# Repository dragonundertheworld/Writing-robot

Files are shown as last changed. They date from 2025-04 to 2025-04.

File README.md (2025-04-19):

# Robotic Pen‑Lifting Mechanism

A modular, servo‑driven pen‑lifting module with a central support bracket, designed for CNC‑style drawing robots, whiteboard plotters, or calligraphy machines. This repository contains CAD models, dimension sheets, and documentation for each major component and its iterative design process.

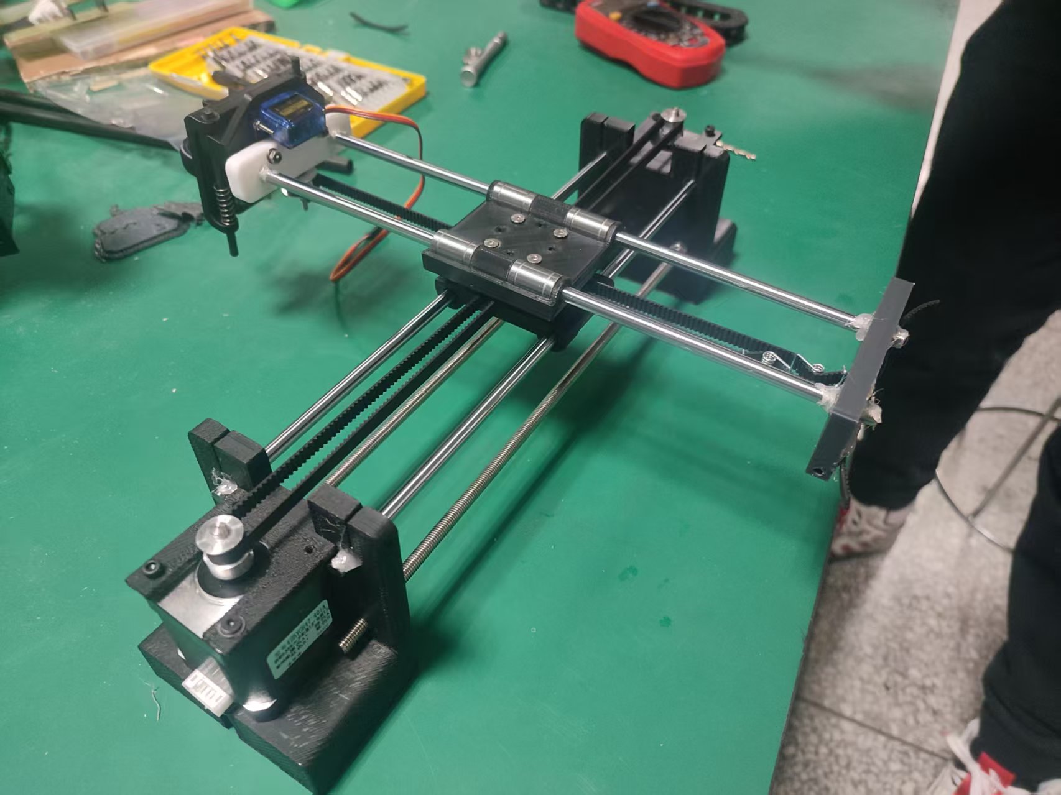
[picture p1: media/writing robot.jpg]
writing robot


Video of writing ["不忘初心"](./media/不忘初心.mp4) and ["你干嘛哎呦"](./media/你干嘛哎呦.mp4)
---

## Table of Contents

- [Robotic Pen‑Lifting Mechanism](#robotic-penlifting-mechanism)
      - [Video of writing "不忘初心" and "你干嘛哎呦"](#video-of-writing-不忘初心-and-你干嘛哎呦)
  - [Table of Contents](#table-of-contents)
  - [Project Overview](#project-overview)
  - [Key Features](#key-features)
  - [Mechanical Design](#mechanical-design)
    - [Central Support Bracket](#central-support-bracket)
    - [Pen‑Lifting Mechanism \& Servo Bracket](#penlifting-mechanism--servo-bracket)
  - [Integration \& Assembly](#integration--assembly)
  - [Bill of Materials](#bill-of-materials)
  - [CAD \& Drawings](#cad--drawings)
  - [Future Improvements](#future-improvements)
  - [License](#license)

---

## Project Overview

This project implements a **pen‑lifting subsystem** that can be mounted on a 2‑axis gantry or delta robot. It consists of:

- A **central support bracket** that holds the lifting assembly above the work surface.
- A **servo‑driven pen‑lift** that raises and lowers the drawing tool with sub‑millimeter precision.
- Modular interfaces for smooth rods and mounting plates, allowing quick integration into larger plotting systems.

---

## Key Features

- **Stable Central Support**  
  High‑rigidity bracket minimizes wobble during fast movements.  
- **Precision Pen Lift**  
  Servo‑cam mechanism provides repeatable up/down strokes.  
- **Modular Interfaces**  
  Standard M3‑hole pattern for linear guides, servos, and carriage plates.  
- **Iterative‑Driven Design**  
  Multiple CAD versions refined for weight, stiffness, and ease of assembly.

---

## Mechanical Design

### Central Support Bracket

1. **Principle**  
   - Acts as the backbone for the pen‑lifting module.  
   - Transfers loads from the carriage to the linear guide rails.  
2. **Dimension Design**  
   - Inner width: 40 mm to clearance standard guide blocks.  
   - Plate thickness: 5 mm aluminum for stiffness.  
   - Servo‑arm clearance zone: 25 mm × 15 mm cut‑out.  
3. **Iteration Process**  
   - **v1.0**: Solid plate—too heavy, resonance at 20 Hz.  
   - **v1.1**: Lightening pockets added—reduced mass by 30%.  
   - **v2.0**: Reinforced rib under servo mount—eliminated flex under 1 kg load.

### Pen‑Lifting Mechanism & Servo Bracket

1. **Lifting Principle**  
   - A high‑torque micro‑servo drives a cam‑follower arm.  
   - Cam profile converts 60° of servo travel into 10 mm vertical stroke.  
2. **Servo Bracket & Pen‑Lift Dimensions**  
   - Servo mount hole spacing: 32 mm × 16 mm (MG90S‑compatible).  
   - Cam arm length: 45 mm from pivot to pen holder.  
   - Guide rod interface: 8 mm bore with PTFE sleeve.  
3. **Component Mating**  
   - **Rod ↔ Pen‑lift arm**: 2 mm set‑screw clamps.  
   - **Pen‑lift arm ↔ Servo bracket**: 3 mm shoulder bolt pivot.  
   - **Rod ↔ Servo bracket**: Linear bushing ensures vertical alignment.  
4. **Iteration Processes**  
   - **Servo Bracket v1.0**: Over‑constrained, binding at extremes.  
   - **Servo Bracket v1.1**: Added +/-0.5 mm clearance pockets.  
   - **Pen‑lift Arm v1.0**: Cam profile too aggressive—jerky motion.  
   - **Pen‑lift Arm v1.1**: Smoothed cam radius; reduced stroke acceleration.

---

## Integration & Assembly

1. **Linear Rail Mounting**  
   - Slide central support onto two parallel 12 mm rails.  
   - Secure with four M3 × 10 mm cap screws.  
2. **Servo & Arm Installation**  
   - Attach servo to bracket using M2.5 hardware.  
   - Fit cam‑arm pivot, align pen holder vertically.  
3. **Pen Holder & Rod**  
   - Slide PTFE sleeve into bracket bore.  
   - Insert 8 mm hardened steel rod; fix pen holder to arm end.  
4. **Cable Routing**  
   - Use zip‑ties along bracket ribs.  
   - Ensure servo cable has >30 mm slack at extremes.

---

## Bill of Materials

| Item | Qty  | Notes |
|---|---|---|
| 5 mm Aluminum Plate (central bracket) | 1 | 100 × 60 mm, 6061‑T6 |
| MG90S Micro‑Servo | 1 | 180° travel, 2.2 kg·cm torque |
| 8 mm Hardened Steel Rod | 1 | Cut to 80 mm length |
| Linear Bushing (8 mm ID) | 2 | PTFE‑lined for smooth lift |
| M3 × 10 mm Cap Screws & T‑nuts | 4 | Rail mounting |
| M2.5 × 8 mm Screws & Nuts | 2 | Servo mount |
| M3 × 6 mm Shoulder Bolt & Washer | 1 | Cam pivot |
| PTFE Sleeve (8 mm ID) | 1 | Bore liner |
| Zip‑ties & Cable Clips | – | For cable management |

---

## CAD & Drawings

- **写字机器人建模/**
  - `中心支架下_Default_sldprt.STEP` — 支撑支架
  - `舵机旋转叶片_默认_sldprt.STEP` — 舵机安装座

---

## Future Improvements

- **Closed‑Loop Control**: Add hall‑sensor feedback for precise pen height.  
- **Quick‑Swap Carriage**: Magnetic couplers for sub‑60 s assembly changes.  
- **Lightweight Composites**: Replace aluminum with carbon‑fiber for weight reduction.  
- **Dampers**: Integrate silicone bumpers to soften pen‑up/down impacts.

---

## License

This work is released under the [MIT License](LICENSE). Feel free to adapt and integrate into your own plotting or drawing systems.

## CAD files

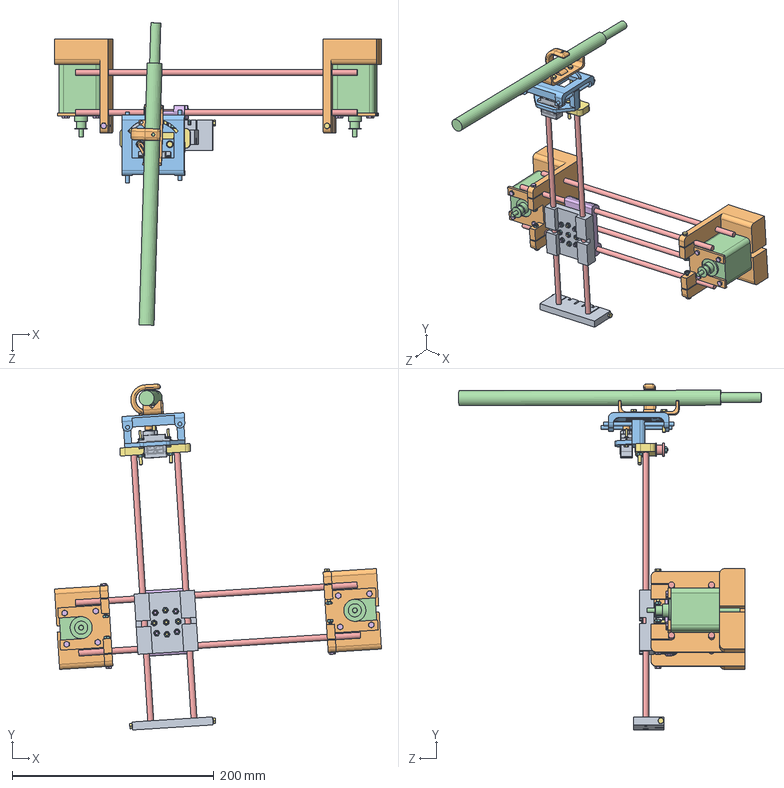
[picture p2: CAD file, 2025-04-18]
assets/写字机器人1.SLDASM
324.4 x 343.2 x 300.2 mm
base
motor_house x 2
Pen Carrige
motor1 x 2
光杆(丝杆) x 6
中心支架下
y_end2
惰轮 x 4
y_end1
Penholder
servoholder2
16齿主动轮 x 2
十六齿惰轮
hexagon head bolts-full thread gb x 15
hexagon head bolts gb x 15
hex nuts, style 1-grades ab gb x 20
SG90 - Micro Servo 9g - Tower Pro.1_Pe_X_87a
舵机旋转叶片
木棍 x 2
毛笔

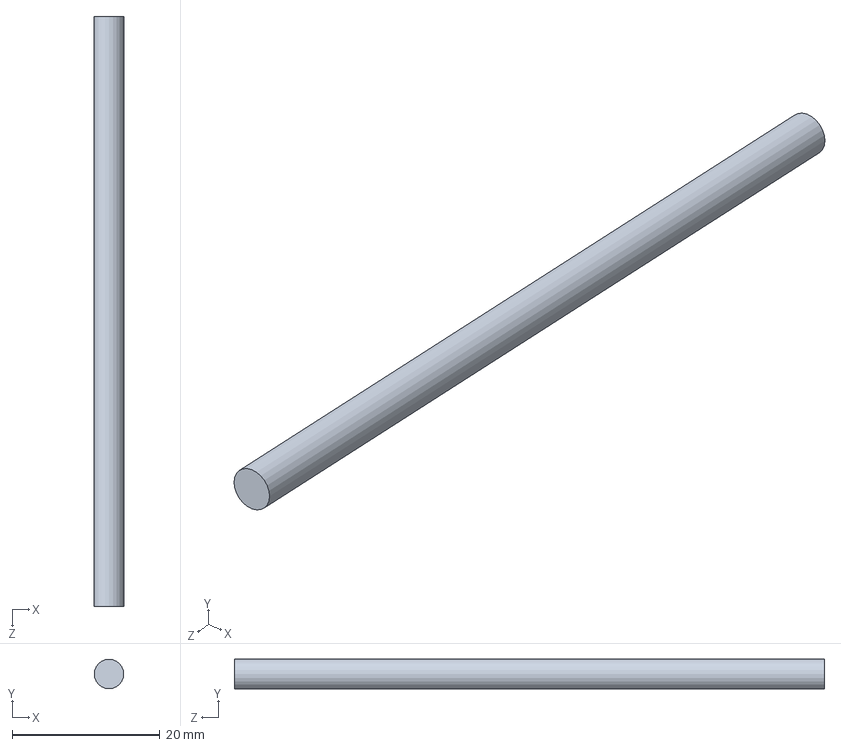
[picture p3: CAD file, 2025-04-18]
assets/木棍.SLDPRT
4.00 x 4.00 x 80.0 mm

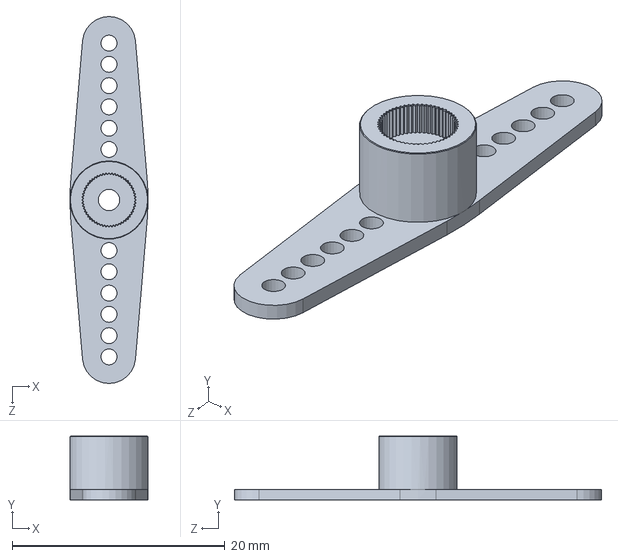
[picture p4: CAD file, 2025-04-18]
assets/舵机旋转叶片.SLDPRT
7.36 x 6.00 x 34.5 mm

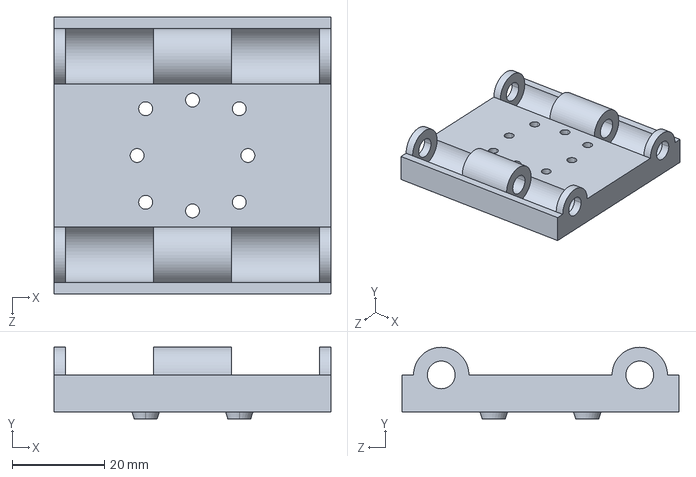
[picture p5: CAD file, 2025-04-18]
assets/base_默认_sldprt.STEP
60.0 x 15.5 x 60.0 mm

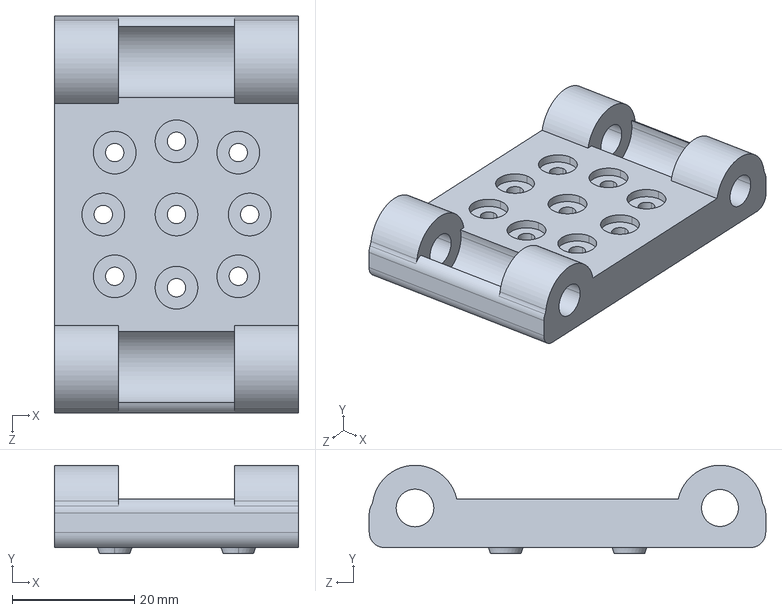
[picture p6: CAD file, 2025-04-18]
assets/中心支架下_Default_sldprt.STEP
40.0 x 14.5 x 65.0 mm

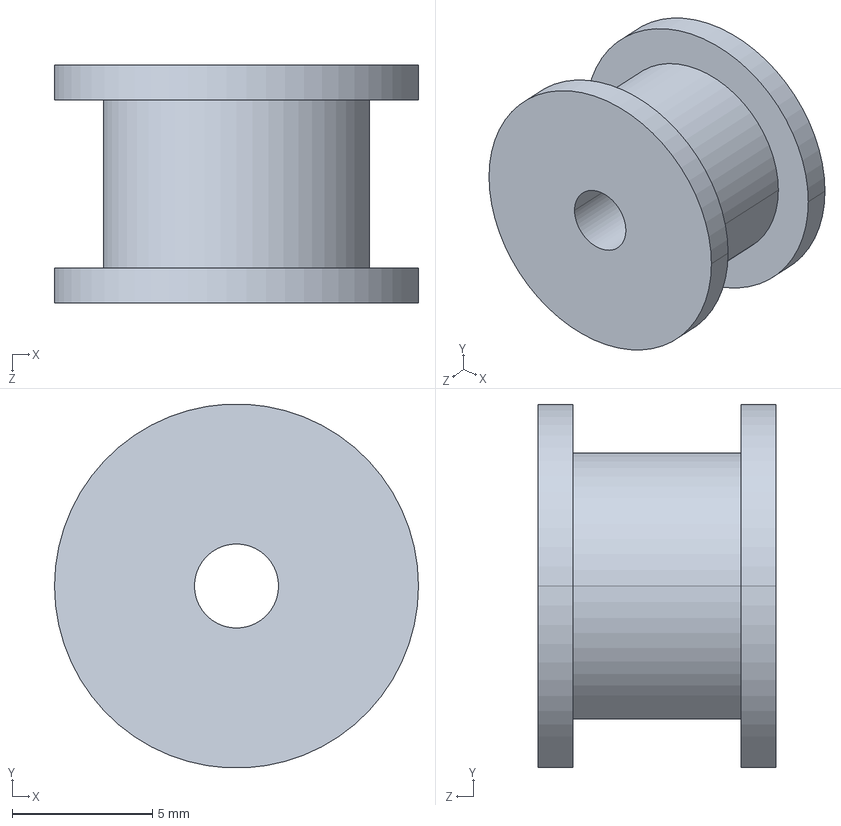
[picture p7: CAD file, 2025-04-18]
assets/惰轮_默认_sldprt.STEP
13.0 x 13.0 x 8.50 mm

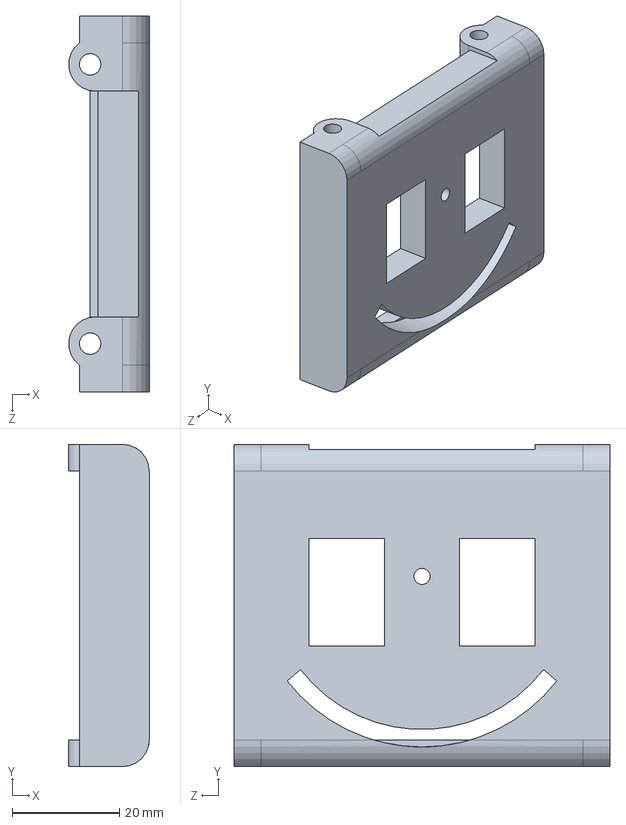
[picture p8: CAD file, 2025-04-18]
assets/Pen Carrige.SLDPRT
15.0 x 60.0 x 70.0 mm

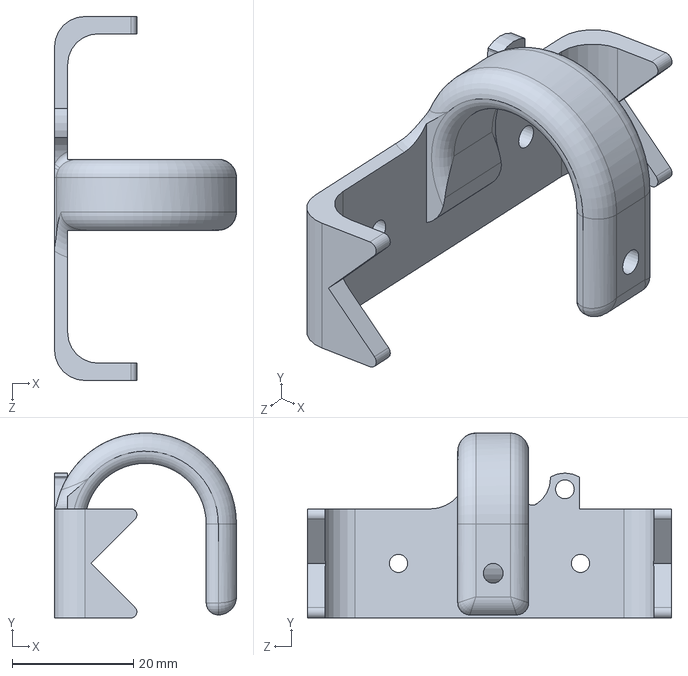
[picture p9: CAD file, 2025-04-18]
assets/Penholder.SLDPRT
30.0 x 30.5 x 60.0 mm

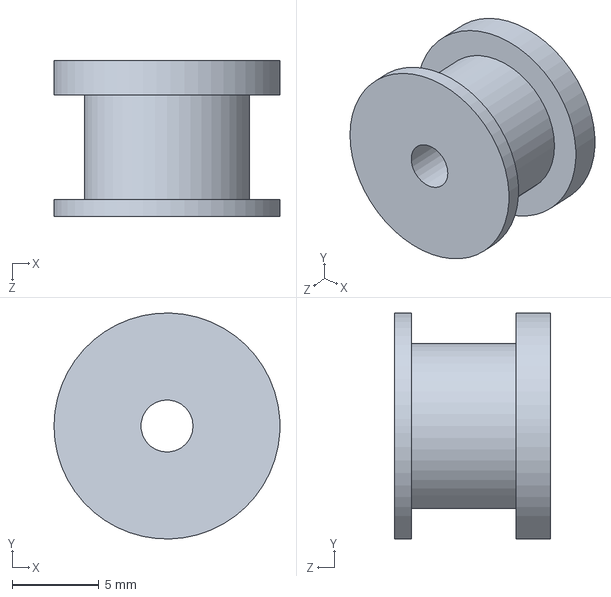
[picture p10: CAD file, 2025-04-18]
assets/十六齿惰轮.SLDPRT
13.0 x 13.0 x 9.00 mm

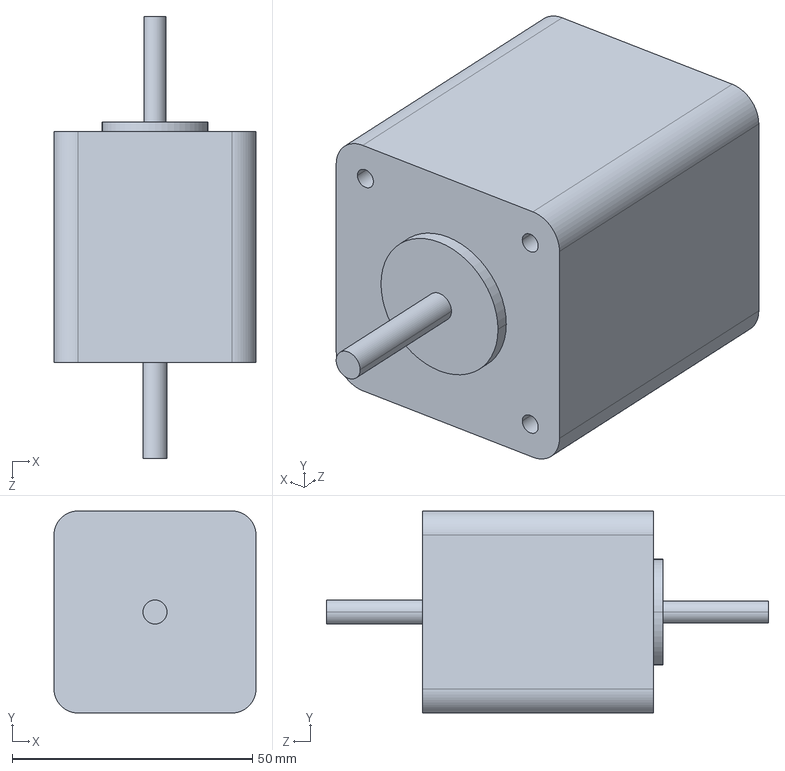
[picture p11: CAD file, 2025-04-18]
assets/motor1_默认_sldprt.STEP
42.0 x 42.0 x 92.0 mm

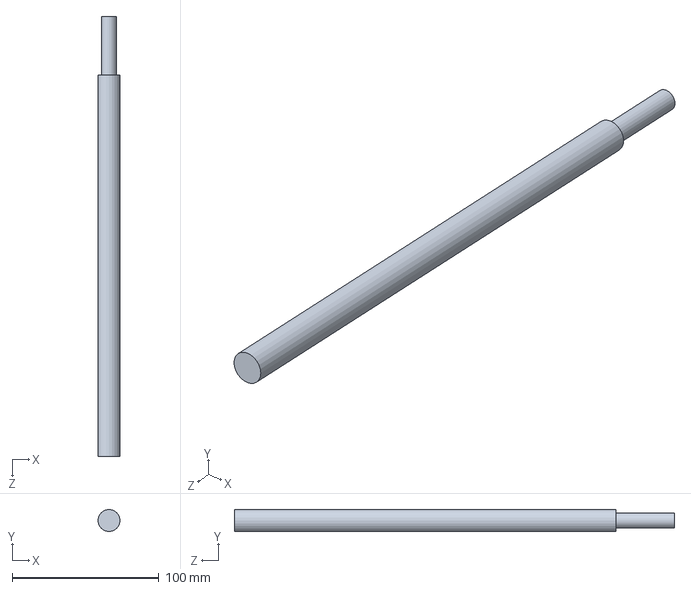
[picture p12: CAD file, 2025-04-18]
assets/毛笔.SLDPRT
15.0 x 15.0 x 300.0 mm

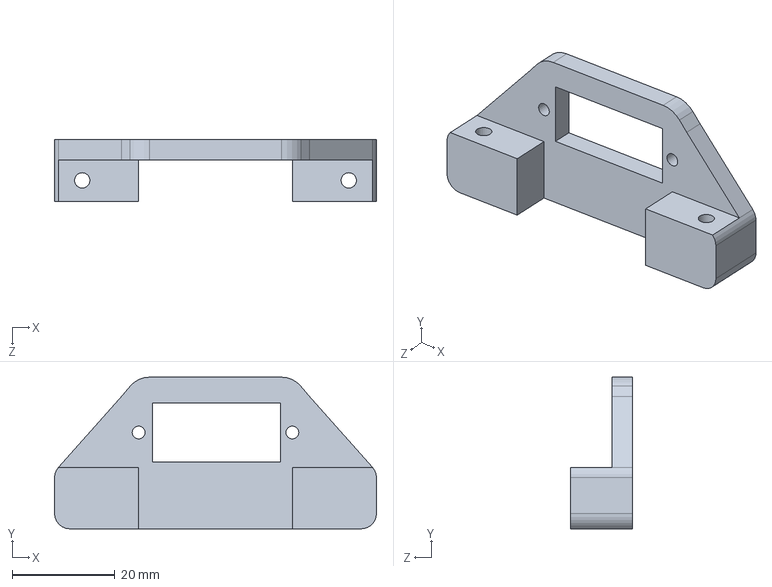
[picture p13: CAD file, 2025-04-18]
assets/servoholder.SLDPRT
62.8 x 29.6 x 12.0 mm

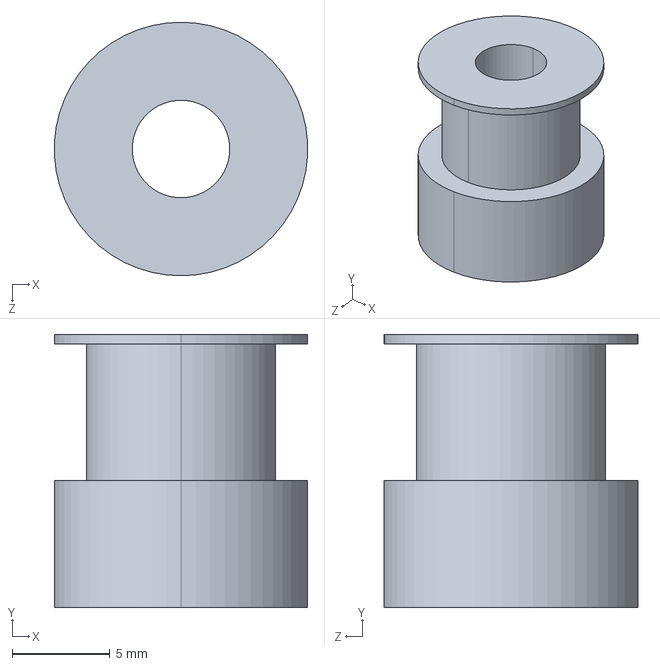
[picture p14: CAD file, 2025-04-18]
assets/16齿主动轮_默认_sldprt.STEP
13.0 x 14.0 x 13.0 mm

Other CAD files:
assets/舵机旋转叶片_默认_sldprt.STEP
assets/中心支架下.SLDPRT
assets/base.SLDPRT
assets/16齿主动轮.SLDPRT
assets/Penholder_默认_sldprt.STEP
assets/Pen Carrige_默认_sldprt.STEP
assets/SG90 - Micro Servo 9g - Tower Pro.1_Pe_X_87a.SLDPRT
assets/SG90 - Micro Servo 9g - Tower Pro.1_Pe_X_87a_默认_sldprt.STEP
assets/hex nuts- style 1-grades ab gb_GB_FASTENER_NUT_SNAB1 M3-N_sldprt.STEP
assets/hexagon head bolts gb_GB_FASTENER_BOLT_SB A M3X20-C_sldprt.STEP
assets/hexagon head bolts gb_GB_FASTENER_BOLT_SB A M3X20-N_sldprt.STEP
assets/hexagon head bolts gb_GB_FASTENER_BOLT_SB A M3X30-N_sldprt.STEP
assets/hexagon head bolts-full thread gb_GB_FASTENER_BOLT_STBAB A M3X30-S_sldprt.STEP
assets/hexagon head bolts-full thread gb_GB_FASTENER_BOLT_STBAB A M3X6-N_sldprt.STEP
assets/hexagon head bolts-full thread gb_PreviewCfg_sldprt.STEP
assets/motor1.SLDPRT
assets/motor_house.SLDPRT
assets/motor_house_默认_sldprt.STEP
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
